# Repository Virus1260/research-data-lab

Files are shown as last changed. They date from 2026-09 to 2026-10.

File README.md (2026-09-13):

# Research Data Lab

> An interactive digital laboratory that transforms dense engineering research dossiers into visual, narrated, playable experiences.





## 🧪 Project #1 — Hosokawa AFD Pharma Freeze Dryer

**The AFD is not a conventional shelf/tray freeze dryer.** It is an agitated, jacketed, downward-conical vessel where product is frozen and dried while being continuously stirred, discharging as loose powder instead of vial cakes.

This interactive lab covers:
- 19 chapters from foundations → physics → build plan
- 8 interactive physics simulators (drag sliders, see real equations live)
- 74-item annotated Bill of Materials
- 34 academic & patent references
- Neural TTS narration for Chapter 03 (with transcript sync)
- Light & dark theme (light by default)

---

## ✨ Features

| Feature | Description |
|---|---|
| **Live Equation Playground** | Interact with Clausius-Clapeyron, sublimation rate, vacuum pumpdown & refrigeration equations |
| **Interactive Simulators** | 8 physics simulators wired to real engineering math |
| **Narration Engine** | Pre-generated audio with sentence-level transcript sync |
| **Light / Dark Theme** | Toggle via header (light default, persisted in `localStorage`) |
| **⌘K Command Palette** | Jump to any chapter, simulator, or BOM item instantly |
| **Proper Tables** | Professional data tables with hover states and filtering |
| **KaTeX Equations** | All formulas rendered with LaTeX precision |
| **Scrollytelling TOC** | Sticky mini-map with active section tracking |

---

## 🚀 Getting Started

```bash
# Clone the repository
git clone https://github.com/YOUR_USERNAME/research-data-lab.git
cd research-data-lab

# Install dependencies
npm install

# Start development server
npm run dev
```

Open [http://localhost:3000](http://localhost:3000) in your browser.

---

## 📁 Project Structure

```
research-data-lab/
├── app/                          # Next.js App Router
│   ├── layout.tsx                # Root layout (ThemeProvider, NarratorProvider)
│   ├── page.tsx                  # Archive — gallery of research capsules
│   └── [project]/
│       ├── page.tsx              # The Lab — project overview console
│       ├── [chapter]/page.tsx    # Exhibit — scrollytelling chapter reader
│       ├── bom/page.tsx          # The Bench — interactive BOM table
│       └── references/page.tsx   # The Shelf — source catalog
│
├── components/
│   ├── layout/
│   │   ├── Header.tsx            # Nav + theme toggle
│   │   ├── ThemeProvider.tsx     # Light/dark context (localStorage)
│   │   └── ThemeScript.tsx       # FOUC prevention inline script
│   ├── exhibit/
│   │   ├── ExhibitReader.tsx     # Markdown → HTML renderer with KaTeX
│   │   ├── KatexEquation.tsx     # LaTeX equation renderer
│   │   └── LawEquationsPlayground.tsx  # 4 live physics playgrounds
│   ├── simulators/               # 8 interactive simulators
│   │   ├── PhaseDiagramExplorer.tsx
│   │   ├── SublimationRateCalculator.tsx
│   │   ├── VacuumPumpdownSimulator.tsx
│   │   ├── CycleProfileScrubber.tsx
│   │   └── ...
│   ├── narrator/                 # Audio narration engine
│   │   ├── NarratorContext.tsx
│   │   └── NarratorDeck.tsx
│   └── command-palette/          # ⌘K search
│
├── research-data/
│   └── hosokawa-afd-freeze-dryer/
│       ├── project.config.ts     # Project metadata & act structure
│       ├── chapters/             # 19 MDX chapter files
│       ├── data/
│       │   ├── bom.json          # 74 BOM line items
│       │   └── references.json   # 34 cited references
│       ├── diagrams/             # 5 technical diagrams
│       └── audio/                # Neural TTS narration + manifests
│
├── lib/
│   ├── content.ts                # Server-side content readers
│   ├── physics.ts                # Physics formula implementations
│   └── types.ts                  # TypeScript interfaces
│
└── scripts/
    ├── generate_narration.py     # Azure Neural TTS pipeline
    ├── export_bom.py             # Excel → JSON BOM export
    └── migrate_chapters.py       # MD → MDX migration
```

---

## 🎨 Design System

**Obsidian Cleanroom** (dark) / **Lab Daylight** (light):

| Token | Dark | Light |
|---|---|---|
| Background | `#08090A` | `#F5F6F8` |
| Panel | `#0D0F12` | `#FFFFFF` |
| Cryo accent | `#7FD4FF` | `#2B8DC8` |
| Amber accent | `#E5A93C` | `#C8830A` |
| Typography | Geist Sans + Geist Mono | Same |

---

## 🔬 Interactive Simulators

1. **Phase Diagram Explorer** (Ch. 02) — Draggable P–T chart with state boundaries
2. **Sublimation Rate Calculator** (Ch. 11) — Heat-duty → drying time
3. **Vacuum Pumpdown Simulator** (Ch. 06/11) — Exponential evacuation curve
4. **Cycle Profile Scrubber** (Ch. 04) — 5-stage process timeline
5. **Comparative Pressure Detector** (Ch. 06) — Pirani vs. capacitance gauge
6. **Refrigeration Load Calculator** (Ch. 11) — Cooling duty & patent spec
7. **AFD Comparison Flip** (Ch. 03) — AFD vs. conventional lyophilizer
8. **Vessel Cross-Section** (Ch. 05) — Interactive 3D vessel exploded view

---

## 📖 Adding a New Research Project

1. Create `research-data/<your-project-slug>/`
2. Add `project.config.ts` (copy from `_template-project/`)
3. Add MDX chapters in `chapters/`
4. Add `data/bom.json` and `data/references.json`
5. Run `npm run dev` — the project auto-appears in the Archive

See [CONTRIBUTING.md](CONTRIBUTING.md) for the full schema.

---

## 🤖 Neural TTS Narration

```bash
pip install edge-tts
python scripts/generate_narration.py <chapter-slug>
# Outputs: public/research-data/<project>/audio/<chapter>.mp3
#          public/research-data/<project>/audio/<chapter>.manifest.json
```

---

## 🧠 Antigravity Brain Path

This project is maintained by the Antigravity IDE. The active brain/context for this project lives at:

```
C:\Users\Shekhar\.gemini\antigravity-ide\brain\c8a63233-3b28-442f-a429-51adf4072fb2\
```

To resume: open the Antigravity IDE and reference conversation `c8a63233-3b28-442f-a429-51adf4072fb2`.

---

## 📄 License

MIT © 2026 Research Data Lab

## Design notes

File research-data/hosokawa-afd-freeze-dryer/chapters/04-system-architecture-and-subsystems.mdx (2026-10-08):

---
title: "System Architecture & 17 Subsystems Overview"
chapterNumber: "04"
slug: "04-system-architecture-and-subsystems"
act: "Foundations & Flowsheets"
actId: "act-1"
readTime: "6 min read"
simulators: ['CycleProfileScrubber']
---

# 04 — System Architecture & 17 Subsystems Overview

::youtube[https://www.youtube.com/watch?v=91mCewt5t38]{title="Deep Dive into Nauta Mixing & Drying Technology - Educational Webinar" channel="HosokawaMicron" duration="47:36" context="Chapter 04 Architecture Deep Dive" caption="Engineering presentation detailing Vrieco-Nauta conical vacuum drying skid architecture, cantilevered drive integration, vacuum tightness, and auxiliary recovery circuits."}

Hosokawa Active Freeze Drying System — Integrated Production Skid

Hosokawa Vrieco-Nauta 5-VDC Complete Pilot Vacuum Dryer Skid

Stirred Freeze Dryer Process Flow Diagram (PFD) — Primary Operating Architecture

Hosokawa Industrial Vacuum Drying Plant Installation Schematic

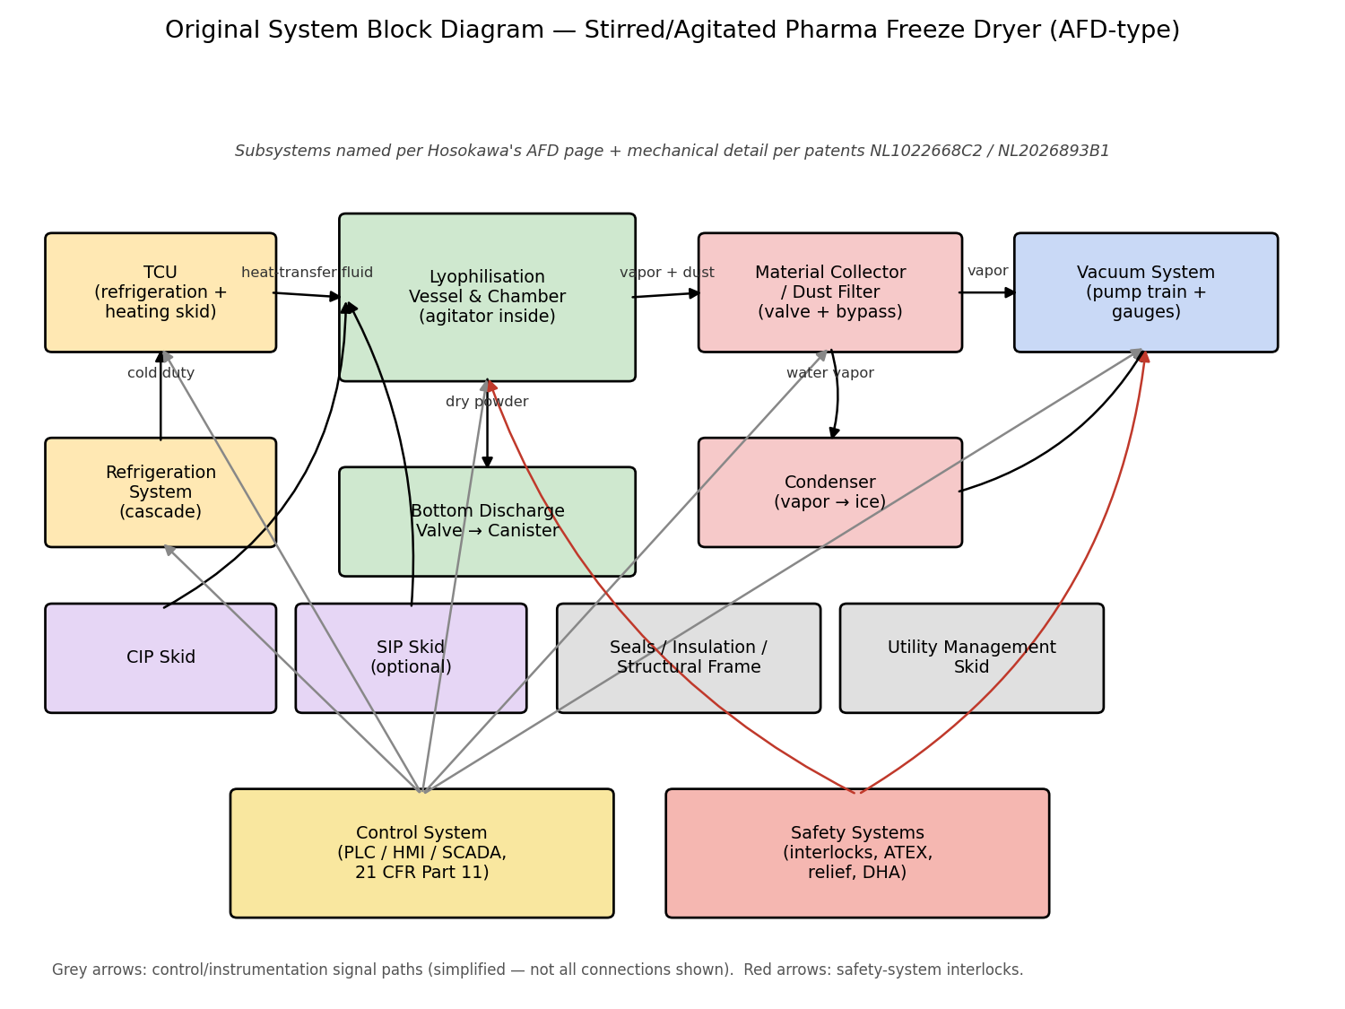
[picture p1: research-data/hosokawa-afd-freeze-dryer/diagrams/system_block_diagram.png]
AFD System Architecture Block Diagram


## 1. Top-Level Subsystem Architecture

Hosokawa Nauta Vacuum Dryer 3D Cutaway Showing Conical Shell and Agitator Dynamics

Vrieco-Nauta Vacuum Dryer Upward and Downward Powder Flow Vector Profile

Vrieco-Nauta Vacuum Dryer System with Pulse-Jet Filter, Condenser & Drain Tank

Hosokawa Controlled Randomization Kinematic Profile

Nauta Mixer Drive Assembly & 1 RPM Orbit Arm Subassembly

Adapting Nauta Conical Mixer for Vacuum Drying Applications

Hosokawa Mixing Spectrum: Nauta (Low Shear) vs CPM (Medium) vs Vitomix

The Hosokawa Active Freeze Dryer comprises 17 integrated mechanical, thermal, vacuum, and automation subsystems. Each subsystem is engineered for cGMP compliance, vacuum integrity down to $0.01\text{ mbar}$, and sterile cleanability:

<SystemArchitectureFlowChart />

---

## 2. Definitive 17-Subsystem Engineering Specification

| # | Subsystem | Operating Function & Physics | Authentic Design Specification | Core Chapter Reference |
|---|---|---|---|---|
| **1** | **Lyophilisation Vessel / Chamber** | Conical pressure/vacuum vessel supporting freeze and sublimation stages | Downward cone with 50% working fill volume constant ($h_{\text{fill}} = 0.794 \cdot h_{\text{cone}}$). Design: FV to +1.5 barg internal; 316L (1.4404) $\text{SF4 } R_a \le 0.38\,\mu\text{m}$. | [Chapter 05: Vessel & Agitator](file:///e:/git_desktop/research-data-lab/research-data/hosokawa-afd-freeze-dryer/chapters/05-vessel-chamber-agitator-and-materials.mdx) |
| **2** | **Agitator & Orbital Drive** | Convective bed circulation and boundary layer renewal | **10:1 Auger (~70 rpm) to Orbit (1–2 rpm) power split**. Cantilevered top-supported screw with **strictly zero bottom bearing**; 3–5 mm wall clearance. | [Chapter 05: Vessel & Agitator](file:///e:/git_desktop/research-data-lab/research-data/hosokawa-afd-freeze-dryer/chapters/05-vessel-chamber-agitator-and-materials.mdx) |
| **3** | **Vessel Jacket & TCU Skid** | Heat transfer fluid circulation for freezing and sublimation | Double jacket (half-pipe coil or dimpled). TCU circulates silicone oil (Syltherm XLT) across $-60^\circ\text{C}$ to $+80^\circ\text{C}$ ($+150^\circ\text{C}$ for SIP). | [Chapter 06: Refrigeration & Vacuum](file:///e:/git_desktop/research-data-lab/research-data/hosokawa-afd-freeze-dryer/chapters/12-refrigeration-vacuum-and-condenser-systems.mdx) |
| **4** | **Refrigeration Cascade** | Provides low-temperature cooling duty to TCU and ice condenser | Two-stage cascade system (R404A / R508B or natural R290 / R170). Evaporator duty sized to pull jacket down to $-55^\circ\text{C}$ within 60 min. | [Chapter 06: Refrigeration & Vacuum](file:///e:/git_desktop/research-data-lab/research-data/hosokawa-afd-freeze-dryer/chapters/12-refrigeration-vacuum-and-condenser-systems.mdx) |
| **5** | **Vacuum Pumping Skid** | Evacuates chamber to process vacuum ($0.05\text{ to }1.5\text{ mbar}$) | Dry screw vacuum pump paired with Roots mechanical booster. Dry design prevents oil backstreaming and handles solvent vapor traces. | [Chapter 06: Refrigeration & Vacuum](file:///e:/git_desktop/research-data-lab/research-data/hosokawa-afd-freeze-dryer/chapters/12-refrigeration-vacuum-and-condenser-systems.mdx) |
| **6** | **Heated Vapor Filter Dome** | Retains fines and routes sublimed vapor without condensation | Overhead dome **heated to +40 °C** via thermal fluid/electrical tracing. Features reverse-pulse dry N₂ blowback (4–6 bar) to dislodge powder cake. | [Chapter 06: Refrigeration & Vacuum](file:///e:/git_desktop/research-data-lab/research-data/hosokawa-afd-freeze-dryer/chapters/12-refrigeration-vacuum-and-condenser-systems.mdx) |
| **7** | **Bottom Discharge Valve** | Containment product discharge with zero dead leg | Sanitary **Ball Segment Valve** with inflatable silicone seal. Full-bore unobstructed flow into sterile transfer split-butterfly isolators. | [Chapter 05: Vessel & Agitator](file:///e:/git_desktop/research-data-lab/research-data/hosokawa-afd-freeze-dryer/chapters/05-vessel-chamber-agitator-and-materials.mdx) |
| **8** | **WIP/CIP Wash Skid** | Automated validated wash cycle without vessel disassembly | **Dual-loop distribution**: 5 cover spray nozzles at **115 mm pitch** (6 bar @ 9 m³/h) impinge drive head/seals; wall nozzles (3 bar) wet steep cone. | [Chapter 07: CIP, SIP & Utilities](file:///e:/git_desktop/research-data-lab/research-data/hosokawa-afd-freeze-dryer/chapters/14-cip-sip-sealing-insulation-and-utilities.mdx) |
| **9** | **SIP Clean Steam Skid** | In-place thermal sterilization of product contact surfaces | Saturated clean steam injection ($\ge 121.1^\circ\text{C}$ / $2.05\text{ bara}$, minimum 30 min hold) with automated condensate trapping at lowest points. | [Chapter 07: CIP, SIP & Utilities](file:///e:/git_desktop/research-data-lab/research-data/hosokawa-afd-freeze-dryer/chapters/14-cip-sip-sealing-insulation-and-utilities.mdx) |
| **10** | **Seals, Gaskets & Insulation** | Thermal barrier and hermetic vacuum boundary maintenance | USP Class VI / FDA PTFE-encapsulated O-rings and FFKM gaskets. Cryogenic-grade cellular glass or aerogel jacket insulation with 304 cladding. | [Chapter 07: CIP, SIP & Utilities](file:///e:/git_desktop/research-data-lab/research-data/hosokawa-afd-freeze-dryer/chapters/14-cip-sip-sealing-insulation-and-utilities.mdx) |
| **11** | **Process Instrumentation** | Continuous monitoring and comparative endpoint determination | Dual pressure measurement: Capacitance manometer (`PIT-101A`, true pressure) + Pirani gauge (`PIT-101B`). 4-wire Pt100 RTDs for bed/jacket profiling. | [Chapter 08: Instrumentation & Controls](file:///e:/git_desktop/research-data-lab/research-data/hosokawa-afd-freeze-dryer/chapters/16-instrumentation-and-electrical-hardware.mdx) |
| **12** | **Sanitary Process Valves & Lines** | Fluid and gas routing with EHEDG drainability | ASME BPE diaphragm valves for CIP/WFI utilities; high-vacuum butterfly and angle valves with position feedback for process gas lines. | [Chapter 08: Instrumentation & Controls](file:///e:/git_desktop/research-data-lab/research-data/hosokawa-afd-freeze-dryer/chapters/16-instrumentation-and-electrical-hardware.mdx) |
| **13** | **BPCS Control Platform** | Automated recipe execution and data historization | PLC-based Basic Process Control System (Siemens S7-1500 or Rockwell ControlLogix) with 21 CFR Part 11 compliant electronic audit trails. | [Chapter 20: Control System](file:///e:/git_desktop/research-data-lab/research-data/hosokawa-afd-freeze-dryer/chapters/17-control-system-architecture.mdx) |
| **14** | **Safety Instrumented System (SIS)** | Independent SIL-rated emergency shutdown and interlocks | Hardwired safety relays or safety PLC guarding against vessel over-pressurization, vacuum implosion, high jacket temp, and agitator stall. | [Chapter 20: Control System](file:///e:/git_desktop/research-data-lab/research-data/hosokawa-afd-freeze-dryer/chapters/17-control-system-architecture.mdx) |
| **15** | **Electrical & ATEX Infrastructure** | Power distribution and hazardous area compliance | VFDs for auger/orbit motors; Zone 20/21 internal ATEX classification for combustible active pharmaceutical dry powders. | [Chapter 08: Instrumentation & Controls](file:///e:/git_desktop/research-data-lab/research-data/hosokawa-afd-freeze-dryer/chapters/16-instrumentation-and-electrical-hardware.mdx) |
| **16** | **Structural Skid & Mezzanine** | Rigidity, vibration damping, and cleanroom integration | Tubular 304 stainless frame; through-the-wall cleanroom bulkhead design isolating technical utilities from GMP gray zone. | [Chapter 08: Instrumentation & Controls](file:///e:/git_desktop/research-data-lab/research-data/hosokawa-afd-freeze-dryer/chapters/16-instrumentation-and-electrical-hardware.mdx) |
| **17** | **Utility Management Skid** | Single-point connection header for plant services | Regulated headers for clean dry compressed air (CDA, 6 barg), gaseous dry nitrogen (N₂, 4–6 barg), WFI, chilled water, and drain cooling. | [Chapter 08: Instrumentation & Controls](file:///e:/git_desktop/research-data-lab/research-data/hosokawa-afd-freeze-dryer/chapters/16-instrumentation-and-electrical-hardware.mdx) |

---

## 3. How the Process Cycle Exercises the Subsystems

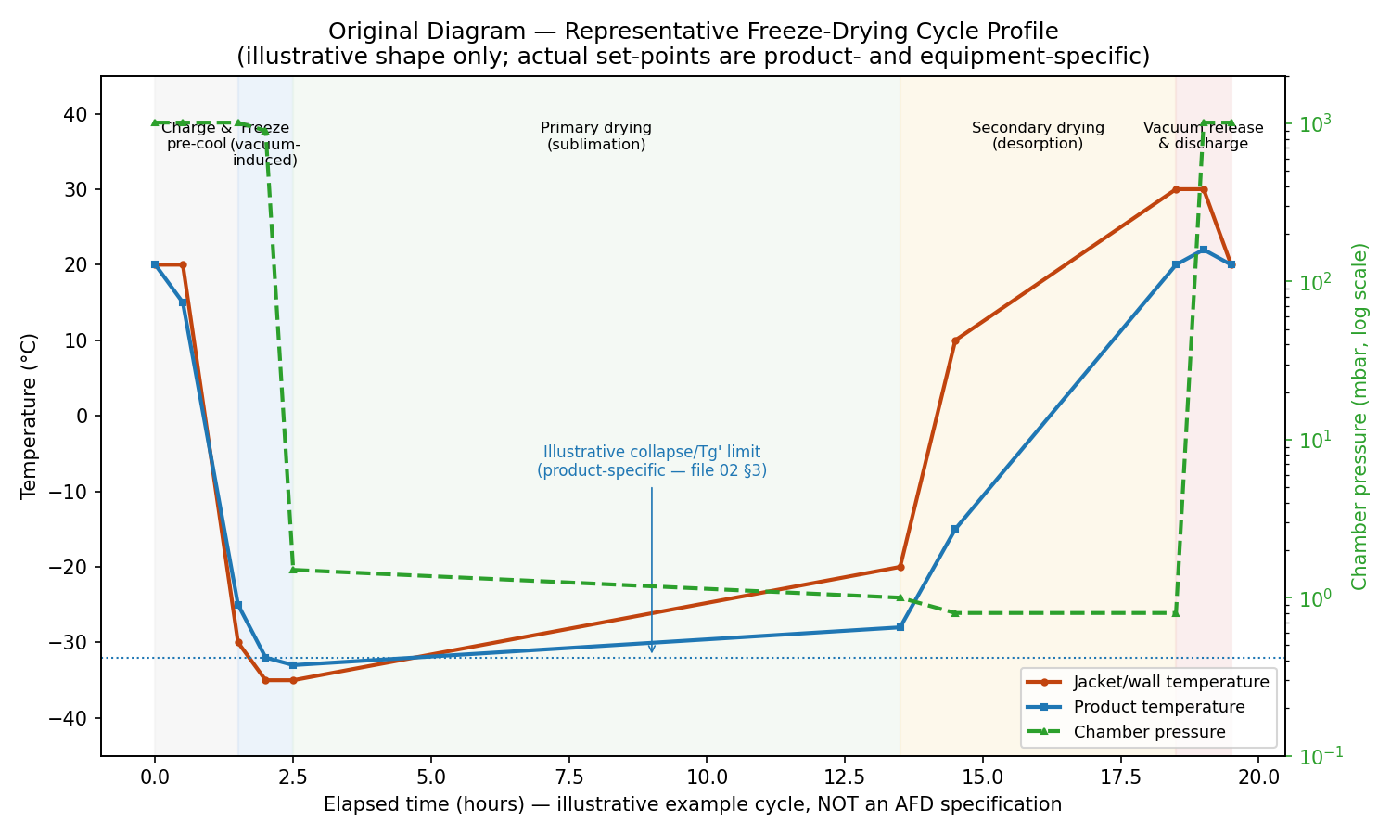
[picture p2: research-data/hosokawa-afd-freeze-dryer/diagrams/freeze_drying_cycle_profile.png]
Representative Freeze Drying Cycle Profile


1. **Aseptic Charging:** API solution or paste is charged via top sanitary port (`N1`) into the purged vessel (pre-inerted with N₂ to $<1\%\text{ O}_2$).
2. **Pre-Cooling & Agitated Granulation:** The TCU chills the vessel jacket to $-40^\circ\text{C}$. The cantilevered auger rotates at low speed (~20–40 rpm), gently tumbling the slurry against the cold wall to prevent bulk freezing into a solid block.
3. **Vacuum Flash Freezing:** The vacuum pump pulls chamber pressure down rapidly. Evaporative surface flash cooling pulls latent heat from within the droplets, fracturing the mass into free-flowing, porous snow granules.
4. **Primary Sublimation:** The vacuum is controlled at $0.05\text{ to }1.5\text{ mbar}$ by throttling valve `PV-102`. The TCU shifts to heating duty ($-10^\circ\text{C}$ to $+20^\circ\text{C}$), delivering $\Delta H_{\text{sub}} = 2,840\text{ kJ/kg}$ into the dynamic bed. Sublimed vapor passes through the +40 °C heated top dome.
5. **Secondary Desorption:** Pressure is lowered to $<0.05\text{ mbar}$ while the jacket is warmed to $+30^\circ\text{C}\text{ to }+40^\circ\text{C}$. Bound moisture desorbs until the Pirani and Capacitance manometer curves converge.
6. **Reverse-Pulse Blowback & Post-Blend:** High-pressure dry N₂ pulses dislodge fines from the filter elements; the auger runs for 5 minutes to homogenize the batch into a single uniform lot.
7. **Sterile Vacuum Release:** The vessel is vented to atmospheric pressure with sterile $0.2\,\mu\text{m}$-filtered nitrogen.
8. **Contained Discharge:** The bottom ball segment valve opens, discharging bulk powder directly into sterile continuous-liner bags or IBC totes.
9. **Automated WIP/CIP & SIP:** The dual-loop CIP skid washes the orbital head (6 bar @ 9 m³/h) and vessel walls (3 bar), followed by 121 °C clean steam sterilization.

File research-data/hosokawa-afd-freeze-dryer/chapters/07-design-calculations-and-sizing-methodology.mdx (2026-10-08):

---
title: "Design Calculations, Sizing Equations & Heat Transfer"
chapterNumber: "07"
slug: "07-design-calculations-and-sizing-methodology"
act: "Mechanical & Vessel Engineering"
actId: "act-2"
readTime: "10 min read"
simulators: ['SublimationRateCalculator', 'RefrigerationLoadCalculator', 'VacuumPumpdownSimulator']
---

# 07 — Design Calculations, Sizing Equations & Heat Transfer

All worked calculations below evaluate a representative **10 kg batch (10 L liquid) in a 20 L nominal vessel**. This batch matches Hosokawa's published 20 L Active Freeze Dryer model (10 L batch capacity, 0.8 kg/h sublimation capacity). This allows direct cross-checking of first-principles physics against commercial performance figures.

## 1. Sublimation rate and thermal duty

The core sublimation energy equation is:

$$Q = \dot{m} \cdot \Delta H_s$$

For ice, latent heat of sublimation is $\Delta H_s \approx 2{,}838\text{ kJ/kg}$.

Hosokawa specifies $\dot{m} = 0.8\text{ kg/h}$ for the 20 L model:

$$\dot{m} = \frac{0.8\text{ kg}}{3600\text{ s}} = 2.222 \times 10^{-4}\text{ kg/s}$$

$$Q = 2.222 \times 10^{-4}\text{ kg/s} \times 2{,}838{,}000\text{ J/kg} \approx 631\text{ W}$$

A thermal heat duty of 631 W sustains 0.8 kg/h sublimation. This thermal load is compact and readily delivered by an electric circulation TCU.

For a 10 kg batch with 90% water content (9.0 kg ice), primary drying time calculates as:

$$t_{\text{drying}} = \frac{9.0\text{ kg}}{0.8\text{ kg/h}} \approx 11.25\text{ hours}$$

This drying duration aligns with Hosokawa's patent range of 10 to 100 hours for industrial batches.

## 2. Required jacket heat-transfer area

Compute heat exchange surface using:

$$Q = U \cdot A \cdot \Delta T \implies A = \frac{Q}{U \cdot \Delta T}$$

- $U$: Overall heat transfer coefficient from jacket fluid to the agitated granular bed. For an actively stirred bed under vacuum, plan for $50\text{ to }200\text{ W/m}^2\text{K}$. Agitation eliminates the stagnant gas gap found in static vial freeze drying.
- $\Delta T$: Temperature difference between the jacket wall and the sublimation front (typically 10 to 30 K).

At $Q = 631\text{ W}$:

| Assumed $U$ ($\text{W/m}^2\text{K}$) | Required Area $A$ ($\text{m}^2$) at $\Delta T = 20\text{ K}$ |
|---|---|
| 50 | 0.63 |
| **100** | **0.32** |
| 150 | 0.21 |
| 200 | 0.16 |

At $U = 100\text{ W/m}^2\text{K}$, required area is $0.32\text{ m}^2$. Sizing a 20 L cone with a 25° half-angle yields exactly $0.32\text{ m}^2$ of internal wetted lateral area.

## 3. Freezing-stage refrigeration duty

Cooling a 10 kg aqueous charge (9.0 kg water, 1.0 kg solids) from +20 °C to -30 °C requires three thermal steps:

$$Q_1 = m \cdot c_{p,\text{liq}} \cdot \Delta T_1 = 10\text{ kg} \times 4.2\text{ kJ/kg}\cdot\text{K} \times 20\text{ K} = 840\text{ kJ}$$

$$Q_2 = m_{\text{water}} \cdot \Delta H_f = 9\text{ kg} \times 334\text{ kJ/kg} = 3{,}006\text{ kJ}$$

$$Q_3 = m \cdot c_{p,\text{ice}} \cdot \Delta T_2 = 10\text{ kg} \times 2.1\text{ kJ/kg}\cdot\text{K} \times 30\text{ K} = 630\text{ kJ}$$

$$\text{Total Thermal Removal } Q_{\text{total}} = 840 + 3{,}006 + 630 = 4{,}476\text{ kJ } (4.48\text{ MJ})$$

Hosokawa patents define optimum freezing rates between 0.1 °C/min and 10 °C/min:

| Target Freeze Time | Cooling Rate (50 °C delta) | Average Refrigeration Duty |
|---|---|---|
| 2.0 h | 0.42 °C/min | 0.62 kW |
| 1.0 h | 0.83 °C/min | 1.24 kW |
| 0.5 h | 1.67 °C/min | 2.49 kW |

Apply a 1.5x to 2.0x engineering factor to account for jacket thermal mass, ambient heat leak, and pump dissipation. Specify a 2.5 to 3.5 kW refrigeration unit.

## 4. Vacuum pump evacuation time

Dry chamber pump-down time follows the volumetric evacuation equation:

$$t = \left(\frac{V}{S}\right) \cdot \ln\left(\frac{P_1}{P_2}\right)$$

For a 20 L ($0.02\text{ m}^3$) dry vessel pumping from 1,013 mbar down to 1 mbar:

| Pump Displacement $S$ | Calculated Evacuation Time |
|---|---|
| 5 $\text{m}^3/\text{h}$ | ~100 s |
| 10 $\text{m}^3/\text{h}$ | ~50 s |
| 20 $\text{m}^3/\text{h}$ | ~25 s |
| 50 $\text{m}^3/\text{h}$ | ~10 s |

This calculation covers initial dry chamber drawdown only. During sublimation, water vapor volumetric flow dominates. At 1 mbar and -20 °C, 0.8 kg/h of vapor equates to over 250 L/s of volumetric gas flow. The cold condenser traps over 95% of this vapor, protecting the dry vacuum pump.

## 5. Agitator motor sizing

Granular agitated bed rheology under freezing vacuum cannot be modeled accurately from first principles alone.
- Hosokawa's 500 L Nauta industrial mixer operates with a 2.2 kW drive.
- A 20 L freeze dryer requires significantly less power (100 W to 250 W continuous).
- Size the drive motor for peak torque during the slush-to-ice phase inversion. Equip the drive with a variable frequency controller (VFD) and monitor motor current continuously.

## 6. External-pressure shell thickness: ASME UG-28

The vessel operates under external vacuum pressure (1.013 bar differential):
- Thin conical shells fail by elastic buckling rather than plastic yielding.
- Sizing follows ASME Section VIII Division 1, paragraph UG-28.
- The engineer assumes an initial wall thickness $t$, computes diameter-to-thickness ($D_o/t$) and length-to-diameter ($L/D_o$) ratios, and retrieves Strain Factor $A$ from Section II Part D Subpart 3 Figure G.
- Using Factor $A$ and design metal temperature, read Stress Factor $B$ from material charts.
- Allowable external working pressure computes as:

$$P_a = \frac{4 \cdot B}{3 \cdot (D_o/t)}$$

Verify that $P_a \ge 1.033\text{ bar}$ plus your required safety margin.

## 7. External pressure tooling methodology: Division 1 vs Division 2 vs PV Elite

Understanding the calculation methodology determines software implementation:

1. **ASME Section VIII Division 1 (UG-28)**:
   - Uses empirical look-up charts. Factor $A$ comes from Figure G. Factor $B$ derives from material stress curves in Section II Part D.
   - These curves represent proprietary ASME compiled data. Do not use AI models to guess curve values.
2. **ASME Section VIII Division 2 (Part 4.4 - Miller Method)**:
   - Formulated as closed-form algebraic equations.
   - Eliminates chart lookups.
   - Readily programmed into automated computational tools.
3. **PV Elite and Commercial Pressure Vessel Solvers**:
   - Industry-standard validated solver for ASME certified code calculations.
   - Integrates ASME material databases and safety factors.
4. **Interactive Vessel Sizing Suite (Built in this Lab)**:
   - Provides preliminary sizing, live geometric exploration, and nozzle coordination.
   - Implements the open, published **Windenburg-Trilling equation** for classical elastic buckling:

$$P_{\text{cr}} = \frac{2.42 \cdot E \cdot (t / D_o)^{5/2}}{(1 - \nu^2)^{3/4} \cdot \left[\frac{L}{D_o} - 0.45 \cdot (t / D_o)^{1/2}\right]}$$

   - Applying a structural safety factor of 3.0 gives the preliminary allowable pressure:

$$P_{\text{allowable}} = \frac{P_{\text{cr}}}{3.0}$$

**Fabrication Rule**: Use the Sizing Suite for rapid dimensional optimization and nozzle scheduling. Perform final certified thickness validation in PV Elite prior to cutting metal.

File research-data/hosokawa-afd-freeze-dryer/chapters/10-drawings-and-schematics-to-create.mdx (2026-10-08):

---
title: "Workshop Fabrication Drawings, Schematics & GA Layouts"
chapterNumber: "10"
slug: "10-drawings-and-schematics-to-create"
act: "Mechanical & Vessel Engineering"
actId: "act-2"
readTime: "3 min read"
simulators: []
---

# 10 — Workshop Fabrication Drawings, Schematics & GA Layouts

The drawings and schematics below (phase diagram, vessel cross-section, system block diagram, refrigeration cascade, cycle profile, P&ID, control architecture, and ISA-88 batch structure) are conceptual/explanatory originals created for this package:

<EngineeringDiagramsGallery />

## Recommended drawing package

| # | Drawing | Purpose | Typical format |
|---|---|---|---|
| 1 | **General arrangement (GA) drawing** | Overall machine footprint, height, service-access clearances, and how all major subsystems (vessel, TCU, vacuum skid, control panel, frame) sit relative to each other | Orthographic views (front/side/top) + isometric |
| 2 | **Vessel fabrication drawing** | Full dimensioned geometry of the conical vessel and jacket: shell thickness, cone angle, cylindrical section height (if used), jacket compartment dimensions, all nozzle/port locations with size and orientation, support-lug locations | Detailed fabrication drawing, code-stamped if pursuing a certified pressure/vacuum vessel |
| 3 | **Agitator drawing** | Mixing-element geometry (screw/paddle/ribbon), shaft dimensions, wall-clearance callouts at multiple heights up the cone, drive-end interface | Fabrication drawing with clearance tolerances explicitly called out (file 05 §3, file 10 §3) |
| 4 | **Process & Instrumentation Diagram (P&ID)** | Every process line, valve, instrument, and interlock in the system, using standard ISA/ANSI instrumentation symbols — the single most important document for both build and later validation/commissioning | Standard P&ID symbology; this is the document file 04's block diagram should evolve into once your design is fixed |
| 5 | **Piping isometrics** | Physical routing of vacuum lines, jacket fluid lines, CIP/SIP lines, and utility lines, with support locations | Standard isometric piping drawings |
| 6 | **Electrical single-line diagram** | Power distribution from main disconnect through to every motor, heater, and control circuit, with breaker/fuse ratings | Standard electrical single-line format |
| 7 | **Control panel layout & wiring diagram** | Physical panel layout and full point-to-point wiring for the PLC/HMI system | Standard electrical panel drawing practice |
| 8 | **I/O list** | Every PLC input and output, tag name, signal type, range, and the field device it connects to | Spreadsheet/table, cross-referenced to the P&ID |
| 9 | **Hazardous-area (ATEX) zoning drawing** | Marked-up GA or floor plan showing Zone 20/21/22 dust boundaries around the material collector/discharge area, and the equipment rating required in each zone | Overlay on the GA drawing, developed alongside the Dust Hazard Analysis (file 09) |
| 10 | **Structural frame/skid drawing** | Frame member sizes, support-point locations matching the vessel's actual lug/support-ring positions, foundation/floor loading | Standard structural fabrication drawing |
| 11 | **CIP/SIP schematic** | Spray coverage, chemical dosing points, steam distribution points and traps (if SIP-equipped) | Schematic, cross-referenced to the P&ID |
| 12 | **Cycle/recipe logic flowchart** | The actual control-system sequence: every step, transition condition, interlock check, and alarm condition through charge → freeze → primary dry → secondary dry → discharge → CIP/SIP | Flowchart, becomes the basis for PLC program structure and later OQ test scripts (file 14) |

## Suggested sequencing

Per the staged fabrication approach in file 10 §4: produce drawings 1–3 first (vessel/agitator geometry) alongside your file-11 sizing calculations, prove the geometry with a non-vacuum mockup, *then* finalize drawing 2 for the real vacuum-rated vessel commission. Drawings 4, 8, and 12 (P&ID, I/O list, cycle logic) should be developed together, since each constrains the others — a common and efficient practice is to draft the cycle logic flowchart first (what does the machine actually need to do, step by step), derive the P&ID from what that logic requires the machine to sense and actuate, and derive the I/O list directly from the finished P&ID.

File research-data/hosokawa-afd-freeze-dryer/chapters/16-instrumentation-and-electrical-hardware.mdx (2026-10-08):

---
title: "Instrumentation Sensors, Electrical Hardware & Skid Frame"
chapterNumber: "16"
slug: "16-instrumentation-and-electrical-hardware"
act: "Electrical, Controls & Safety Automation"
actId: "act-4"
readTime: "6 min read"
simulators: []
---

# 16 — Instrumentation Sensors, Electrical Hardware & Skid Frame

## 1. Process Instrumentation Architecture

| Measurement | Primary Sensor & Loop Tag | Functional Principle & Operating Metric |
|---|---|---|
| **Chamber Absolute Pressure** | Capacitance Manometer (`PIT-101A`) | Diaphragm deflection measuring true mechanical pressure ($0.01 - 10\text{ mbar}$) independently of gas composition. Drives vacuum throttle valve `PV-102`. |
| **Comparative Diagnostic Pressure** | Pirani Thermal Gauge (`PIT-101B`) | Heated filament gauge; reads ~1.6× higher when pure water vapor dominates. Convergence of `PIT-101B` with `PIT-101A` detects sublimation completion. |
| **Condenser Pressure** | Capacitance + Pirani Pair (`PIT-201A/B`) | Monitors condenser vapor load and ice accumulation; enables chamber-to-condenser pressure delta monitoring. |
| **Jacket Supply & Return Temperature** | 4-Wire Pt100 RTDs (`TT-201`, `TT-202`) | Feeds TCU temperature control loop (`TIC-201`) modulating thermal fluid mixing across $-60^\circ\text{C}\text{ to }+80^\circ\text{C}$. |
| **Dynamic Bed Temperature** | Fast-Response Thermocouple Rake (`TT-101`) | Measures core bed temperature; interlocked to ensure product stays below collapse temperature ($T_{\text{bed}} < T_c$). |
| **Heated Top Dome Temperature** | Pt100 RTD (`TT-102`) | Feeds dome heater loop (`TIC-102`), maintaining dome wall at **+40 °C** to prevent water vapor condensation and filter cake blinding. |
| **Agitator Kinematic Feedback** | Torque Transducer / Current (`JIT-101`) | Monitors 10:1 auger drive torque; rising torque indicates slurry crystallization during vacuum flash freezing. |
| **Filter Differential Pressure** | Differential Transmitter (`PDT-102`) | Monitors pressure drop across porous filter media ($\Delta P \ge 50\text{ mbar}$ triggers reverse N₂ blowback `XV-104`). |
| **WIP/CIP Cover Ring Pressure & Flow** | Sanitary Transmitter (`PIT-701`, `FT-701`) | Confirms 6.0 bar @ 9.0 m³/hr to the 5 fixed spray nozzles (115 mm pitch) over the orbital drive head per Hosokawa Drawing `8390105_1`. |
| **WIP/CIP Wall Wash Pressure** | Sanitary Transmitter (`PIT-702`) | Confirms 3.0 bar wash water supply to downward-angled cone wall wetting nozzles per Hosokawa Drawing `8390106_1`. |
| **SIP Sterilization Temperature** | Multi-Point RTD Sensors (`TT-501` to `TT-506`) | Cold spot monitoring during $121.1^\circ\text{C}$ steam sterilization (vessel bottom, discharge valve, and filter exhaust). |

---

## 2. Sanitary Process & Vacuum Valve Selection

- **Vacuum Throttling & Bypass Valves (`PV-102`, `XV-103`):** High-vacuum bellow-sealed angle and butterfly valves with fast pneumatic positioning, managing vapor evacuation and powder recirculation per Hosokawa patent NL2026893B1.
- **Reverse-Pulse Blowback Solenoid (`XV-104`):** High-speed pneumatic valve delivering 4–6 bar dry nitrogen pulses to dislodge collected powder fines from the overhead filter elements.
- **Sanitary Ball Segment Valve (`XV-105`):** Pneumatically operated bottom discharge valve with an inflatable USP Class VI elastomer seal, delivering zero dead space and hermetic vacuum retention.
- **Sanitary Utility Valves (`FV-701`, `FV-702`):** ASME BPE compliant diaphragm valves for CIP distribution, electropolished 316L with PTFE diaphragms.
- **Sterile Gas Break Valve (`XV-106`):** Spring-return fail-closed valve fed with $0.2\,\mu\text{m}$ sterile-filtered nitrogen for controlled atmospheric recovery.

## 3. Control system (PLC/HMI/SCADA)

Hosokawa states explicitly: "**Control system, 21 CFR Part 11 compliant**." Generic architecture for a system like this, consistent with both the AFD's stated compliance target and standard industrial-automation practice:

- **PLC** (programmable logic controller) executes the actual recipe logic: sequencing through freeze/vacuum-draw/primary-dry/secondary-dry/discharge/CIP/SIP steps, reading all instrumentation, driving all valves and drives, and enforcing interlocks (see file 09).
- **HMI** (human-machine interface) — operator screen for recipe selection, live trending of pressure/temperature, alarm display, and manual override where permitted.
- **Data historian / SCADA layer** — logs every batch's process data continuously, which is what makes GMP batch-record generation and regulatory compliance possible at all; this is also where **21 CFR Part 11** requirements bite hardest (see below).
- **GAMP 5** (ISPE's "Good Automated Manufacturing Practice," version 5) is the risk-based framework the pharma industry uses to validate this class of computerized system — it categorizes software (from off-the-shelf infrastructure through configured/customized applications) and scales validation rigor accordingly, rather than demanding the same exhaustive testing for every line of code regardless of risk.
- **21 CFR Part 11** governs electronic records and electronic signatures specifically: audit trails that cannot be altered or deleted, secure user access levels, electronic signatures tied to specific actions (e.g., batch release), and record retention. This is a *regulatory* requirement layered on top of the *engineering* PLC/HMI/historian system — a system can be technically well-built and still fail a Part 11 assessment if, e.g., audit trails can be disabled by an operator, or electronic signatures aren't properly bound to the record they approve. File 14 covers this distinction (build it right vs. prove it's right) in depth.
- For a prototype/educational build, a modern industrial PLC (Siemens S7-1200/1500, Allen-Bradley CompactLogix, or similar) with a standard HMI panel gives you the same architecture pattern at a fraction of the validation overhead — you simply won't (and, per file 14, legally shouldn't) claim GMP/Part 11 compliance for it without the full qualification and software-validation program that requires.

## 4. Electrical system

- **Motor drives**: agitator drive motor (with VFD for speed control, given the freeze/dry-stage speed differences the patents imply), TCU pump and compressor motors, vacuum pump motors — all standard industrial motor/VFD selection, no freeze-dryer-specific electrical technology involved.
- **ATEX-rated equipment** required in any zone where combustible dust is present at meaningful concentration — most relevantly, around the material collector, filter housing, and product discharge/collection point, where dry, fine pharmaceutical powder is directly handled. See file 09 for the hazard basis; practically, this means selecting motors, sensors, junction boxes, and lighting in that zone with the appropriate Zone 20/21/22 dust rating (per the ATEX equipment-category system) rather than standard industrial-rated hardware.
- **Control power segregation**: standard industrial-panel practice — separate, clearly labeled circuits for control logic (24VDC typical) vs. motor/heater power, with appropriately rated disconnects and e-stop circuits (see file 09) wired independently of the PLC logic so an emergency stop functions even if the PLC itself has faulted.

## 5. Structural frame

Conical Mixer Structural Mezzanine Platform & Load Cell Skid System

- A **skid/frame** supports the vessel, its jacket, the agitator drive assembly above the lid, and (depending on layout) the material collector and vacuum piping.
- Given the vessel's cone-point-down orientation and top-mounted drive, the frame's key structural jobs are: (1) carrying the vessel's dead weight plus full product load at the frame's support points (typically a support ring or lugs partway up the conical shell, not the point-down tip); (2) resisting the agitator drive's reaction torque without transmitting objectionable vibration into the vessel/agitator wall-clearance tolerance (file 05 §3); and (3) providing safe operator access — a platform or steps if the lid/top fittings sit above comfortable reach height, which they will on any vessel above roughly the 60–100 L size range per the Nauta-mixer height-vs-volume table in file 03 §3.
- **Vibration isolation** between rotating equipment (agitator drive, vacuum pumps, refrigeration compressors) and the frame is worth designing in from the start — both for instrument reading stability (a vibrating capacitance manometer or torque sensor is a noisy signal) and for the agitator's tight wall-clearance tolerance, which vibration can effectively close to zero at the worst moment.

## 6. Piping

- **Process/vacuum piping**: sized for the pump's rated flow at the expected operating pressure (see file 11's vacuum pump-down calculation) — vacuum piping in particular should be kept as short and large-diameter as practical, since conductance losses in a low-pressure gas line scale unfavorably with length and unfavorably with the fourth power of a reduction in diameter (standard vacuum-engineering practice, not freeze-dryer-specific).
- **Jacket/TCU piping**: sized for the heat-transfer fluid's flow rate and viscosity at the coldest operating temperature (silicone oil viscosity rises substantially as it approaches −55 °C, which can meaningfully derate a pump's real flow delivery versus its room-temperature-water rating — worth checking against the specific fluid's datasheet rather than assuming).
- **Utility piping** (CIP water, compressed air, steam if SIP-equipped) sized per standard industrial practice for the respective utility.
- All product-contact and CIP/SIP-wetted piping should follow the same **ASME BPE sanitary tube/fitting practice** as the vessel itself (file 05 §4) — orbital-welded (not threaded or manually TIG-stitched) joints, crevice-free fittings, and consistent slope/drainability so no wash or rinse fluid can pool.

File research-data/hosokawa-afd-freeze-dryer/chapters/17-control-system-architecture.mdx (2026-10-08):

---
title: "PLC / SCADA Control Architecture & Industrial Network"
chapterNumber: "17"
slug: "17-control-system-architecture"
act: "Electrical, Controls & Safety Automation"
actId: "act-4"
readTime: "5 min read"
simulators: []
---

# 17 — PLC / SCADA Control Architecture & Industrial Network

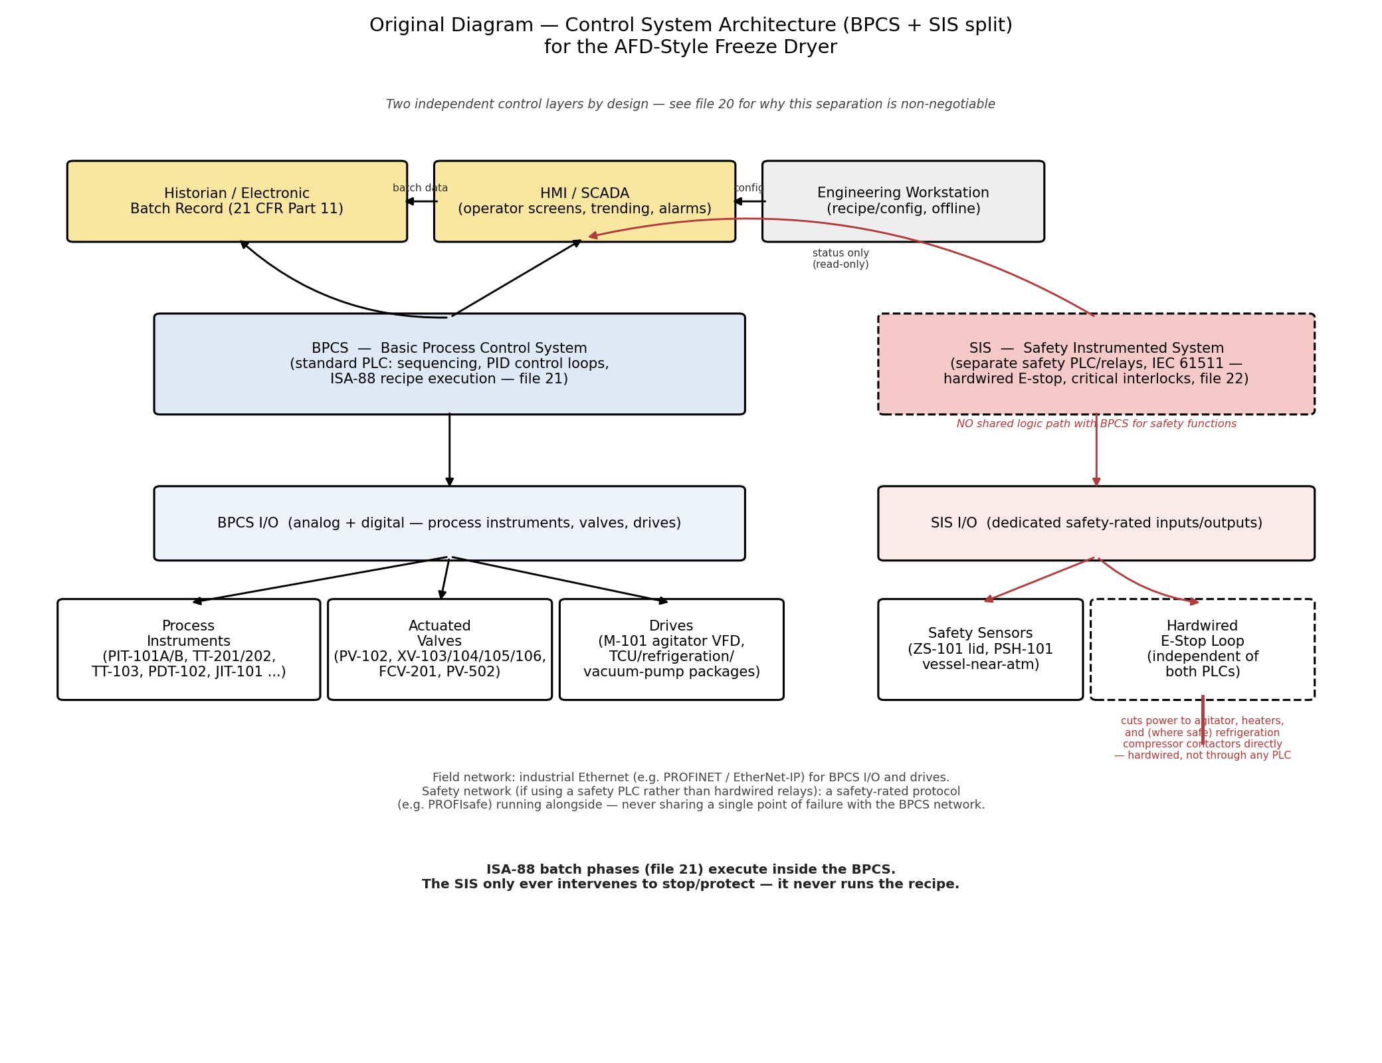
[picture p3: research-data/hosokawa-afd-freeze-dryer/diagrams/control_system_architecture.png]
Control System Architecture — BPCS vs SIS


<AutomationHierarchyChart />

## 1. The one idea that makes everything else make sense

A modern industrial control system for equipment like this is really **two separate systems wearing one HMI screen**:

1. **BPCS — Basic Process Control System.** The "normal" PLC. It runs the recipe, holds temperatures and pressures at setpoint, opens and closes valves in sequence, and logs data. If it glitches, the worst case is a ruined batch.
2. **SIS — Safety Instrumented System.** A separate, simpler, independent system whose *only* job is to force the equipment into a safe state when something specific and dangerous happens — lid opened under vacuum, emergency stop pressed, oxygen depleted in the room. If the BPCS completely fails or freezes, the SIS still works, because it was never depending on the BPCS in the first place.

This split isn't extra bureaucracy — it's the entire point. **IEC 61511**, the international standard for safety instrumented systems in the process industries, exists precisely because history is full of incidents where a single control system was asked to both run the process *and* protect people from it, and a single software bug or logic error took out both jobs at once. Keeping them physically and logically separate means one failure mode can't do that.

Concretely, on this machine: the emergency stop loop (`ESD-001`) is **hardwired** — a physical relay circuit that cuts power to the agitator, heaters, and (where safe to do so) the refrigeration compressor contactors directly. It does not pass through the PLC's software at any point. Even if the BPCS PLC has completely crashed, pressing that button still works.

## 2. The four layers, bottom to top

1. **Field devices** — the actual instruments and valves on the P&ID (file 19): `PIT-101A/B`, `TT-201/202`, `JIT-101`, `PV-102`, `XV-103/104/105/106`, etc. Split cleanly by which system owns them — ordinary process instruments belong to the BPCS; `ZS-101`, `PSH-101`, and the E-stop loop belong to the SIS and nothing else.
2. **I/O** — where field signals physically land: analog input/output cards for continuous signals (4–20 mA, RTD), digital input/output for on/off signals (limit switches, run feedback, valve open/closed confirmation). The SIS uses its own dedicated, safety-rated I/O — never sharing a card or a rack with BPCS I/O, so a BPCS I/O card fault can't also blind the safety system.
3. **Controllers** — the BPCS PLC (running the ISA-88 recipe logic from file 21) and the SIS (either a certified safety PLC or, for a smaller/prototype build, simple hardwired safety relays — both are legitimate approaches; a safety PLC is more flexible as the interlock list grows, hardwired relays are simpler to verify and are a very reasonable choice for a first build).
4. **Supervisory layer** — HMI/SCADA (what the operator actually looks at: live values, trends, alarms, manual controls where permitted), a historian/electronic batch record (every batch's data, logged continuously — this is what a real GMP batch record is built from, file 14), and an engineering workstation for offline recipe/configuration work.

Hosokawa Micron SCADA HMI Mimic Screen — Main Process Overview & Motor Controls

## 3. What talks to what (and, just as importantly, what doesn't)

- The BPCS talks to the HMI/SCADA and the historian freely — that's its whole job.
- The SIS talks to the HMI **read-only** — an operator can *see* that a safety interlock has tripped and why, but the HMI (and by extension, the BPCS) has no path to override or reset a safety trip through software. Resetting a genuine safety trip is normally a deliberate physical/procedural action, precisely so a software bug can't quietly clear a safety condition on its own.
- The SIS does not execute any part of the recipe. It only ever watches a small number of specific, safety-relevant signals and forces specific safe-state actions when they occur (file 22's cause-and-effect matrix is the complete list of what those are on this machine).

## 4. Networks

- **Field network for the BPCS**: a standard industrial Ethernet protocol — PROFINET or EtherNet/IP are the two you'll see most often — connecting the PLC to remote I/O, VFDs (like the agitator drive), and the HMI.
- **Safety network**, if you use a safety PLC rather than hardwired relays: a safety-rated protocol running alongside the standard network (PROFIsafe is the common example on a PROFINET-based system) — designed so that even sharing physical cabling, the safety data is checksummed and validated independently, and a corrupted BPCS message can never be mistaken for a valid safety command.
- For a first build, it's completely reasonable to skip a safety PLC and safety network entirely and use simple, physically separate hardwired relay logic for the handful of SIS functions in file 22 — this is simpler to build, simpler to verify by testing, and loses none of the core "independent from the BPCS" property that actually matters. Move to a safety PLC later if the interlock list grows enough that relay wiring becomes unwieldy.

## 5. Where the ISA-88 recipe logic (file 21) actually lives

All of it sits inside the BPCS, as software. The SIS never runs a step of the recipe — it only ever watches and, if needed, stops. Keeping this boundary completely clean (recipe logic in the BPCS, protection logic in the SIS, and nothing shared between them) is the single habit most worth building correctly from your very first prototype, because retrofitting the separation into a system that was built without it is far harder than building it in from day one.

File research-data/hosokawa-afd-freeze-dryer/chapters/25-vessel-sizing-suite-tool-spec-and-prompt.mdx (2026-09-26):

---
title: "Vessel Sizing Suite: Tool Specification & Parametric Engineering Architecture"
chapterNumber: "25"
slug: "25-vessel-sizing-suite-tool-spec-and-prompt"
act: "Automation, P&ID & CAD"
actId: "act-5"
readTime: "12 min read"
simulators: ['VesselSizingSuite']
---

# 25: Vessel Sizing Suite: Tool Specification & Parametric Engineering Architecture

This specification formalizes the physical models from Chapter 05 §1a/§1b and Chapter 11 §6-7 into an operational, interactive mechanical sizing architecture: a parametric conical freeze-dryer suite matching Hosokawa's published 10-model industrial spectrum (1 L to 1,500 L nominal).

## 1. What this tool is and what it is not

**It is**: a real-time, interactive engineering explorer for conical freeze-dryer vessel geometry across the full industrial size range (1 L to 1,500 L nominal). It establishes dynamic coupling between batch working volume, cone half-angle ($\alpha = 20^\circ$ to $35^\circ$), top major diameter ($D_{\text{major}}$), apex minor diameter ($D_{\text{minor}}$), height stack, lateral transfer area, 50 mm annular jacket hydrodynamics, ASME Section VIII UG-32 formed heads, and elastic vacuum buckling stability. It exports dimensionally certified nozzle schedules directly for CAD modeling and P&ID integration (Chapter 24).

**It is not**: a substitute for certified ASME BPVC Section VIII Division 1 or Division 2 stress calculations performed in licensed software such as PV Elite. Chapter 11 §7 codifies this clear boundary: this sizing suite generates preliminary mechanical architecture, geometric envelopes, and thermal feasibility bounds. Final nozzle reinforcement pads, knuckle high-stress concentrations, seismic anchoring, and certified full-vacuum buckling margins must be stamped in PV Elite prior to cutting metal.

---

## 2. Interactive Core Calculation Workbenches

Every equation in this sizing methodology is dynamic and interactive. Adjust the sliders below to explore the non-linear coupling across vessel dimensions, non-linear fill heights, heat transfer margins, ASME heads, and external pressure limits.

### 2.1 Conical Shell Geometry Workbench (Height, Diameter, Slant & Lateral Area)

In a conical vessel, volume $V$ is governed by total height $h$ and half-angle $\alpha$:
$$V = \frac{\pi}{3} \cdot \tan^2(\alpha) \cdot h^3 \implies h = \left[\frac{3 \cdot V}{\pi \cdot \tan^2(\alpha)}\right]^{1/3}$$

The interactive workbench below solves the complete geometric state vector ($h$, $D$, $L_{\text{slant}}$, and $A_{\text{lat}}$) for any volume and angle:

::ConeGeometryWorkbench

---

### 2.2 The Non-Linear Cone Fill Height Insight (V ∝ h³)

In a conical dryer, volume scales with the **cube** of vertical height. While a cylindrical vessel fills linearly ($V \propto h$), a cone concentrates volume at the top. Filling a conical vessel to 50% working volume raises the liquid surface to:
$$h_{\text{fill}} = h \cdot (0.5)^{1/3} \approx 0.794 \cdot h \quad (79.4\%\text{ of total height})$$

This leaves only $20.6\%$ linear freeboard. Attempting to fill to $80\%$ volume pushes the liquid surface to $92.8\%$ of total height (leaving only $7.2\%$ freeboard), suffocating the orbiting orbital screw agitator, blocking subliming vapor escape paths, and triggering severe dry cake entrainment into the top vacuum filter plenum.

::NonlinearFillHeightWorkbench

---

### 2.3 Sublimation Heat Duty & Annular Heat-Transfer Area Cross-Check

The sublimation process requires continuous latent heat input through the conical jacketed wall ($Q = \dot{m} \cdot \Delta H_s$). The jacket surface area must satisfy:
$$A_{\text{req}} = \frac{Q}{U \cdot \Delta T}$$

If the conical lateral surface area $A_{\text{lat}}$ is insufficient to transfer this thermal load, the vessel design requires a straight cylindrical shell extension at the top to close the thermal deficit. Explore the trade-offs below:

::JacketSurfaceAreaWorkbench

---

### 2.4 ASME Section VIII UG-32 Dished Head Thickness Calculator

The top vessel closure must withstand internal clean steam-in-place (SIP) pressure up to 3.0 to 3.5 barg at 135°C under ASME BPVC Section VIII Division 1 UG-32 rules:
- **Torispherical (ASME Flanged & Dished)**: $L = D$, $r = 0.06D$, stress coefficient $M = \frac{3 + \sqrt{L/r}}{4} \approx 1.77$:
  $$t = \frac{P \cdot L \cdot M}{2SE - 0.2P}$$
- **2:1 Semi-Ellipsoidal**: $L = 0.9D$, $r = 0.17D$, stress coefficient $K = 1.0$:
  $$t = \frac{P \cdot D \cdot K}{2SE - 0.2P}$$
- **Flat Bolted Blind Flange**: Structurally inefficient under vacuum; ASME guidelines restrict flat heads to diameters $\le 300\text{ mm}$.

::HeadThicknessWorkbench

---

### 2.5 Preliminary Vacuum Buckling & External Pressure Analysis

During freeze-drying, the vessel operates under deep vacuum (0.01 to 0.1 mbar) while the thermal fluid jacket operates at positive pressure (1.5 to 3.0 barg), producing severe net external collapsing pressure. Classical elastic shell buckling is governed by the Windenburg-Trilling formulation:
$$P_{\text{cr}} = \frac{2.42 \cdot E \cdot (t / D_o)^{5/2}}{(1 - \nu^2)^{3/4} \cdot \left[\frac{L}{D_o} - 0.45 \cdot (t / D_o)^{1/2}\right]}$$

With an ASME Section VIII design factor of safety $\text{FS} = 3.0$, allowable external vacuum pressure $P_{\text{allowable}} = P_{\text{cr}} / 3.0$ must strictly exceed atmospheric differential pressure (1.013 bar).

::BucklingPressureWorkbench

---

## 3. Parametric Vessel Sizing & Fabrication Suite (Live CAD Simulator)

Below is the live, unified parametric sizing application. It integrates the 10 Hosokawa model presets, dynamic cone half-angle modulation, formed head profile selection, full 50 mm annular jacket modeling, and an adaptive engineering fabrication sketch with dual-theme Paper CAD and Deep Blueprint modes.

::VesselSizingSuite

---

## 4. Humanized Technical Specification & Engineering Matrices

### 4.1 Hosokawa AFD Published Model Range & Working Volume Matrix

Hosokawa Micron markets 10 standard production sizes of the AFD Conical Freeze-Dryer. In all standard models, the maximum allowable batch working volume is set to **exactly 50% of the nominal cone volume** to safeguard the orbital screw agitator mechanics and ensure unimpeded vapor sublimation disengagement.

| Model Designation | Nominal Volume $V_{\text{nom}}$ | Max Batch Volume $V_{\text{work}}$ (50%) | Sublimation Capacity $\dot{m}$ | Top Major Diameter $D_{\text{major}}$ | Cone Height $h_{\text{cone}}$ ($\alpha=25^\circ$) | Conical Lateral Area $A_{\text{lat}}$ | Apex Discharge Bore | Industrial Application Scale |
| :--- | :--- | :--- | :--- | :--- | :--- | :--- | :--- | :--- |
| **AFD-1** | 1.0 L | 0.5 L | 0.10 kg/h | 14.1 cm (141 mm) | 15.1 cm (151 mm) | 0.036 m² | DN80 (3" Tri-Clamp) | Benchtop R&D / Feasibility |
| **AFD-5** | 5.0 L | 2.5 L | 0.30 kg/h | 24.1 cm (241 mm) | 25.8 cm (258 mm) | 0.106 m² | DN80 (3" Tri-Clamp) | Formulation Development |
| **AFD-20** | 20.0 L | 10.0 L | 0.80 kg/h | 38.2 cm (382 mm) | 41.0 cm (410 mm) | 0.267 m² | DN100 (4" Tri-Clamp) | Pilot Plant / Clinical Phase I |
| **AFD-60** | 60.0 L | 30.0 L | 1.70 kg/h | 55.1 cm (551 mm) | 59.1 cm (591 mm) | 0.555 m² | DN100 (4" Tri-Clamp) | Small Batch cGMP Production |
| **AFD-100** | 100.0 L | 50.0 L | 2.20 kg/h | 65.4 cm (654 mm) | 70.1 cm (701 mm) | 0.778 m² | DN150 (6" Tri-Clamp) | Commercial High-Potency cGMP |
| **AFD-200** | 200.0 L | 100.0 L | 3.40 kg/h | 82.4 cm (824 mm) | 88.3 cm (883 mm) | 1.236 m² | DN150 (6" Tri-Clamp) | Commercial API Freeze-Drying |
| **AFD-500** | 500.0 L | 250.0 L | 7.20 kg/h | 111.8 cm (1118 mm) | 119.8 cm (1198 mm) | 2.276 m² | DN150 (6" Tri-Clamp) | High-Volume Active Bulk |
| **AFD-800** | 800.0 L | 400.0 L | 9.90 kg/h | 130.8 cm (1308 mm) | 140.2 cm (1402 mm) | 3.118 m² | DN200 (8" Tri-Clamp) | Large Scale Bulk Processing |
| **AFD-1000** | 1,000.0 L | 500.0 L | 11.40 kg/h | 140.8 cm (1408 mm) | 150.9 cm (1509 mm) | 3.618 m² | DN200 (8" Tri-Clamp) | High-Throughput Antibiotics |
| **AFD-1500** | 1,500.0 L | 750.0 L | 13.70 kg/h | 161.2 cm (1612 mm) | 172.8 cm (1728 mm) | 4.741 m² | DN250 (10" Flange) | Maximum Industrial Monoblock |

---

### 4.2 Governing Mechanical Sizing Formulation Matrix

This table summarizes the physical formulations implemented across the sizing engine:

| Module Identifier | Physical Principle | Governing Formula | Adjustable Inputs | Primary Output Metric | Verification Criterion |
| :--- | :--- | :--- | :--- | :--- | :--- |
| **MOD-01** | Cone Geometry | $h = \left[\frac{3V}{\pi \tan^2(\alpha)}\right]^{1/3}$ | Volume $V$ (L), Half-angle $\alpha$ ($20^\circ\text{--}35^\circ$) | Height $h$ (cm), Top Dia $D$ (cm) | Aspect ratio $h/D = 0.5 / \tan(\alpha)$ |
| **MOD-02** | Non-Linear Fill | $h_{\text{fill}} = h \cdot (f)^{1/3}$ | Batch fill fraction $f = V_{\text{batch}} / V_{\text{nom}}$ | Fill height $h_{\text{fill}}$, Freeboard % | $f = 0.5 \implies h_{\text{fill}} = 79.4\% \cdot h$ |
| **MOD-03** | Thermal Duty | $Q = \dot{m} \cdot \Delta H_s$ | Sublimation rate $\dot{m}$ (kg/h), $\Delta H_s = 2838\text{ kJ/kg}$ | Heat duty $Q$ (Watts) | Heat balance check |
| **MOD-04** | Area Adequacy | $A_{\text{req}} = \frac{Q}{U \cdot \Delta T}$ | Heat coeff $U$ (W/m²K), Jacket $\Delta T$ (°C) | Required area $A_{\text{req}}$ (m²) | $A_{\text{cone}} \ge A_{\text{req}}$ or add straight shell |
| **MOD-05** | Formed Head | $t = \frac{P \cdot L \cdot M}{2SE - 0.2P}$ | Pressure $P$ (barg), Stress $S$ (MPa), Joint $E$ | Minimum thickness $t$ (mm) | ASME Sec VIII Div 1 UG-32 |
| **MOD-06** | Annular Space | $V_{\text{jkt}} = \pi \bar{D} \cdot \delta \cdot L_s$ | Annular gap $\delta$ (default 50 mm), Wall $t_j$ | Holdup volume (L), Mass (kg) | Velocity $v \approx 1.5\text{ m/s}$ (LPM flow) |
| **MOD-07** | Elastic Buckling | Windenburg-Trilling Eq. | Thickness $t$ (mm), Equivalent $D_o$, Length $L$ | $P_{\text{cr}}$ (bar), Allowable $P_a$ (bar) | $P_a = P_{\text{cr}} / 3.0 \ge 1.013\text{ bar}$ |

---

### 4.3 Top Closure Head Types & ASME UG-32/UG-33 Compliance Matrix

The choice of top dish head impacts clean steam SIP containment, formed depth, cleanability, and vacuum collapse resistance:

| Head Type | Geometric Profile & Radii | ASME Stress Factor | Vacuum Collapse Equivalent | Forming Rise Depth $h_{\text{dish}}$ | Engineering Assessment & Selection Rule |
| :--- | :--- | :--- | :--- | :--- | :--- |
| **Torispherical (ASME F&D)** | Crown radius $L = D$, Knuckle radius $r = 0.06D$ | $M = \frac{3 + \sqrt{L/r}}{4} \approx 1.77$ | Equivalent sphere radius $R_o = L = D$ | $h \approx 0.169 \cdot D$ | **Recommended Practical Default**: Low profile, standard dishing dies, excellent cleanability, proven in sterile pharma. |
| **2:1 Semi-Ellipsoidal** | True 2:1 ellipse ($a = D/2, b = D/4$) | $K = \frac{1}{6}\left[2 + (D/2h)^2\right] = 1.0$ | Equivalent sphere radius $R_o \approx 0.90 \cdot D$ | $h = 0.250 \cdot D$ | **Maximum Pressure Efficiency**: Lowest required wall thickness, but higher formed rise adds vertical clearance demand. |
| **Flat Bolted Flange** | Flat circular plate with bolt circle | $C = 0.20$ to $0.33$ | Extreme bending moment under vacuum | $h = 0.000\text{ mm}$ (Flat) | **Restricted Envelope**: Unacceptable for diameters $> 300\text{ mm}$ under full vacuum due to excessive plate thickness ($> 25\text{ mm}$) and bolt load stresses. |

---

### 4.4 50 mm Annular Jacket Heat Transfer & Hydrodynamics Matrix

The annular space between the inner conical shell (product contact 316L) and the outer jacket shell (304L) is engineered with a **50 mm nominal radial gap** to achieve optimal hydrodynamic performance:

| Sizing Parameter | Engineering Value | Governing Physical Law | Engineering Rationale for 50 mm Annular Gap |
| :--- | :--- | :--- | :--- |
| **Nominal Radial Gap ($\delta$)** | **50 mm** (Adjustable 20 to 100 mm) | Geometric radial clearance | A 50 mm gap maintains ideal thermal fluid velocity ($1.2\text{ to }1.8\text{ m/s}$) at standard TCU pump flow rates (30 to 80 LPM), guaranteeing fully developed turbulent convection ($Re > 4,000$) without excessive pressure drops. |
| **Inner Cone OD** | $D_{\text{major}} + 2 \cdot t_{\text{shell}}$ ($+8\text{ mm}$) | Product contact wall | 4.0 mm to 6.0 mm 316L (EN 1.4404) electropolished to $Ra \le 0.2\,\mu\text{m}$. |
| **Jacket Inner Diameter (ID)** | $\text{Cone OD} + 2 \cdot \delta$ ($+100\text{ mm}$ for 50 mm gap) | Annular envelope | The jacket inner wall is spaced exactly 50 mm radially from the cone outer wall. |
| **Jacket Outer Diameter (OD)** | $\text{Jacket ID} + 2 \cdot t_{\text{jacket}}$ ($+6\text{ mm}$) | Outer pressure containment | 3.0 mm to 5.0 mm 304L (EN 1.4307) outer structural jacket shell. |
| **Thermal Fluid Holdup** | $V_{\text{jkt}} \approx A_{\text{lat}} \cdot \delta$ (Liters) | Annular fluid volume | For AFD-20 with $A_{\text{lat}} = 0.267\text{ m²}$ and 50 mm gap, fluid holdup is $\approx 13.4\text{ L}$ ($12.3\text{ kg}$ Syltherm XLT), ensuring rapid dynamic temperature response. |
| **Inlet / Outlet Orientation** | Bottom Apex (J1 In) $\rightarrow$ Top Flange (J2 Out) | Natural convection and venting | Fluid enters at the lowest apex cone elevation (J1) and discharges at the top flange ring (J2) to continuously purge entrained air bubbles and prevent vapor locking. |

---

## 5. CAD Export & Equipment Schedule JSON Schema

The tool generates machine-readable equipment nozzle schedules matching `cad_equipment_nozzle_schedule.json` for SolidWorks and Siemens NX parametric modeling:

```json
{
  "equipment_id": "AFD-V-101",
  "model_designation": "Hosokawa AFD-20",
  "nominal_volume_liters": 20.0,
  "max_batch_volume_liters": 10.0,
  "batch_volume_ratio": 0.50,
  "geometry": {
    "cone_half_angle_deg": 25.0,
    "top_inside_diameter_mm": 382.4,
    "bottom_apex_inside_diameter_mm": 100.0,
    "conical_shell_height_mm": 410.0,
    "dish_head_depth_mm": 64.6,
    "bottom_discharge_spool_height_mm": 60.0,
    "total_fabrication_height_mm": 534.6,
    "conical_lateral_area_m2": 0.267,
    "liquid_fill_height_50pct_mm": 325.5,
    "freeboard_height_mm": 84.5
  },
  "annular_jacket": {
    "annular_gap_mm": 50.0,
    "jacket_inside_diameter_mm": 490.4,
    "jacket_outside_diameter_mm": 496.4,
    "jacket_fluid_volume_liters": 13.35,
    "thermal_duty_watts": 631,
    "heat_transfer_area_required_m2": 0.315,
    "recommended_flow_rate_lpm": 25.0
  },
  "asme_bpvc_design_basis": {
    "code_standard": "ASME BPVC Section VIII Division 1 (UG-32 / UG-33)",
    "design_pressure_internal_barg": 3.0,
    "design_pressure_external_vacuum_bar": 1.013,
    "head_type": "Torispherical ASME F&D (M=1.77)",
    "calculated_minimum_head_thickness_mm": 1.84,
    "windenburg_trilling_allowable_external_bar": 5.42,
    "safety_factor": 3.0,
    "status": "PASSES_PRELIMINARY_BUCKLING"
  }
}
```

---

## 6. Architectural Role within the Research Lab

This sizing suite connects engineering theory from Chapter 05 (conical vessel mechanics and agitator kinematics) and Chapter 11 (thermodynamic sublimation balances and PV Elite code boundaries) directly into production artifacts:

1. **Chapter 13 (Engineering Drawings)**: Seeds dimensional elevations for general arrangement CAD drawings.
2. **Chapter 24 (CAD Nozzle Schedule)**: Feeds exact nozzle coordinates for process ports (N1 vacuum vapor, N2 product feed, N3 CIP sprayballs, N4 sampling port, N5 illumination sight glass, N6 vacuum release, N7 rupture disc, J1 jacket inlet, J2 jacket outlet, and bottom discharge port).
3. **P&ID Skid Automation**: Supplies fluid holdup volumes to the Temperature Control Unit (TCU) heat exchanger skid for cascade temperature loop tuning.

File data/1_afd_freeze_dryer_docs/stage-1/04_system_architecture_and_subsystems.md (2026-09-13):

# 04 — System Architecture & Subsystem Breakdown

See `diagrams/system_block_diagram.png` for an original block diagram of the full system described below.

## Top-level subsystem map

This structure follows Hosokawa's own named subsystem list (from the AFD page and the general drying-systems page) combined with the mechanical detail from the two patents (file 03), organized the way you'd actually plan a build:

```
                       ┌─────────────────────────┐
                       │   Control System (PLC/   │
                       │   HMI, 21 CFR Part 11)   │
                       └────────────┬─────────────┘
                                    │ I/O
        ┌────────────┬─────────────┼─────────────┬─────────────┐
        │             │             │             │             │
   ┌────▼───┐   ┌─────▼─────┐ ┌────▼────┐  ┌─────▼─────┐ ┌─────▼──────┐
   │  TCU   │   │  Vessel/  │ │ Vacuum  │  │  Material  │ │ CIP/SIP    │
   │ (heat/ │──▶│  Chamber  │▶│  Path   │─▶│ Collector  │▶│  Skid      │
   │  cool) │   │ + Agitator│ │ (valve, │  │ + Vacuum   │ │            │
   └────────┘   └─────┬─────┘ │ bypass) │  │   Pump     │ └────────────┘
                       │       └─────────┘  └────────────┘
                 ┌─────▼─────┐
                 │  Bottom   │
                 │ Discharge │
                 │  Valve    │──▶ Product Collection Canister
                 └───────────┘

   Utility Management Skid: interfaces all of the above to
   plant electricity, compressed air/nitrogen, process water,
   steam (if SIP), chilled water/glycol, and drains.
```

## Subsystem list, with what each one does and where it's covered in this package

| # | Subsystem | Function | Covered in |
|---|---|---|---|
| 1 | **Lyophilisation vessel/chamber** | Downward-conical, jacketed pressure/vacuum vessel that holds the product through freeze + dry | File 05 |
| 2 | **Agitator & drive** | Orbiting screw/paddle/ribbon; scrapes vessel wall; magnetic or sealed drive | File 05 |
| 3 | **Vessel jacket & TCU** | Double-jacketed wall; external skid circulates heat-transfer fluid for both cooling (freeze) and heating (dry) | File 06 |
| 4 | **Refrigeration system** | Supplies cold duty to TCU and (in classic designs) the condenser | File 06 |
| 5 | **Vacuum system** | Pump train, gauges, isolation valves, piping — pulls and holds process vacuum | File 06 |
| 6 | **Material collector / dust filter** | External filter housing in the vacuum line; recovers dry powder from the vapor stream; AFD-specific valve/bypass arrangement | File 06 |
| 7 | **Bottom discharge valve** | Ball-segment (or equivalent) valve for full product dump at end of cycle | File 05 |
| 8 | **CIP system** | Spray balls/rotary nozzles, chemical dosing, water rinse cycles | File 07 |
| 9 | **SIP system (optional)** | Clean steam generation/distribution for in-place sterilization | File 07 |
| 10 | **Seals, gaskets, insulation** | Elastomer door/lid seals, agitator shaft seal or magnetic coupling, external insulation jacket | File 07 |
| 11 | **Instrumentation** | Pressure gauges (Pirani + capacitance manometer), temperature (product/jacket/condenser), level, torque | File 08 |
| 12 | **Valves & piping** | Sanitary process valves, vacuum isolation valves, utility piping | File 08 |
| 13 | **Control system (PLC/HMI/SCADA)** | Recipe execution, data logging, alarms, 21 CFR Part 11 electronic records | File 08 |
| 14 | **Electrical system** | Motor drives, control power, ATEX-rated equipment in dust zones | File 08 |
| 15 | **Structural frame** | Skid/frame supporting the vessel, drive, and services; access platform if tall | File 08 |
| 16 | **Utility Management Skid** | Single interface point to plant electricity, compressed air/N₂, process water, steam, chilled water, drains | File 08 |
| 17 | **Safety systems** | Vacuum/pressure relief, interlocks, ATEX-rated components in dust zones, e-stop circuits | File 09 |

## How the process cycle exercises each subsystem

See `diagrams/freeze_drying_cycle_profile.png` for an original time/temperature/pressure chart of a representative cycle.

1. **Charge** — product loaded into vessel (top port, per patent drawings), lid closed and clamped/sealed.
2. **Pre-cool / freeze** — TCU circulates cold fluid through jacket; agitator running slowly; vessel at or near atmospheric pressure initially, per NL2026893B1's description ("temperature within the freeze-drying chamber is lowered to a temperature close to and above the freezing temperature... by introducing a heat-exchanging medium into the double-jacketed vessel wall"), then vacuum is drawn to induce final freezing.
3. **Vacuum draw / vacuum-induced freezing** — vacuum system pulls chamber down; as pressure drops, product temperature drops further (evaporative/flash cooling) until freezing is complete and the mass has broken into free-flowing granular ice, assisted by continuous agitation.
4. **Primary drying** — jacket temperature raised under TCU control while vacuum is held; agitator continues at low speed; sublimed vapor flows out through the material-collector valve path (open early, closed/bypass later per NL2026893B1); dried powder accumulates in the collector.
5. **Secondary drying** — jacket temperature raised further; vacuum held; remaining bound moisture desorbed.
6. **End-of-cycle blowback & post-blend** — filter purge dislodges collected powder into the heated recipient; valve reopens to return collected material to vessel for post-blending into one uniform batch (per NL2026893B1).
7. **Vacuum release** — controlled break to atmosphere (via sterile air/N₂ if aseptic).
8. **Discharge** — bottom valve opens; product drops to collection canister.
9. **CIP (and SIP if required)** — automated wash/sterilize cycle before next batch.

## Why this maps well to a workshop build

Every one of the 17 subsystems above is either (a) a mechanical/plumbing assembly a well-equipped workshop can fabricate or adapt commercial components for, or (b) a component you should simply buy (vacuum pump, PLC, sensors, seals). File 10 draws that make/buy line item-by-item; file 12 turns it into an actual BOM.

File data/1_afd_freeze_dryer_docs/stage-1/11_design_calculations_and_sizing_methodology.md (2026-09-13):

# 11 — Design Calculations & Sizing Methodology

All worked numbers below use a **representative 10 kg batch (≈10 L) of a 90% water solution, in a nominal ~20 L vessel** — chosen because it lines up with a size Hosokawa itself publishes indicative performance for on the AFD page (their "20 L model" is quoted with a 10 L max batch volume and an indicative sublimation capacity of 0.8 kg/h), letting us **cross-check a first-principles calculation against Hosokawa's own published figure** without needing any proprietary data. Every number below is illustrative engineering methodology, not a specification for your build — rerun these with your own batch size, product properties, and measured (not assumed) heat-transfer coefficients once you have a prototype to test.

## 1. Sublimation rate ↔ heat duty (cross-checked against Hosokawa's published figure)

The core relationship (file 02 §3):
```
Q = (dm/dt) × ΔHs
```
`ΔHs` (latent heat of sublimation of ice) ≈ 2,838 kJ/kg.

Plugging in **Hosokawa's own published 0.8 kg/h** for the 20 L model:
```
dm/dt = 0.8 kg/h = 2.222×10⁻⁴ kg/s
Q = 2.222×10⁻⁴ × 2,838,000 J/kg ≈ 631 W
```
**A ~630 W jacket heat duty to sustain 0.8 kg/h sublimation is a small, entirely buildable number** for a 20 L-class unit — well within a single-phase electric heater or a modest hot/cold TCU circuit. This is a useful sanity check: if your own design's required heat duty for a similar batch size comes out wildly different (say, tens of kW), that's a strong signal to re-examine your assumptions before building anything.

**Time to sublime the batch's water content**, at that rate: for 9 kg of water (90% of a 10 kg batch) at 0.8 kg/h, primary drying takes **≈11.25 h** — consistent with the "hours to days" range generic literature gives for primary drying, and with Hosokawa's own 2003 patent's "10–100 hours for a 50 L charge" figure (a larger charge, so a longer time, is directionally consistent).

## 2. Required jacket heat-transfer area

```
Q = U × A × ΔT   →   A = Q / (U × ΔT)
```
- `U` = overall heat transfer coefficient, jacket wall → agitated product. **This is genuinely product- and design-specific and cannot be looked up reliably** — it depends on wall material/thickness, agitation intensity, particle size, and chamber pressure (gas-phase conduction across any micro-gaps is pressure-dependent, same physics as file 02's vial-heat-transfer-coefficient discussion). A reasonable **first-pass planning range for an actively agitated, direct-contact granular bed is roughly 50–200 W/m²·K** — meaningfully better than the static-vial gas-gap coefficients reported in the Pikal-model literature (which are often only single digits to tens of W/m²·K, precisely *because* a static vial's heat path crosses a poorly-conducting gas gap that agitation is specifically designed to eliminate), but this must be measured on your own prototype, not assumed for a final design.
- `ΔT` = jacket-wall-to-product temperature differential; **10–30 °C** is a reasonable planning range, consistent with typical primary-drying shelf-to-product differentials reported in the shelf-freeze-dryer literature.

At `Q ≈ 631 W`:

| Assumed U (W/m²K) | Required area for ΔT = 20 °C |
|---|---|
| 50 | 0.63 m² |
| 100 | 0.32 m² |
| 150 | 0.21 m² |
| 200 | 0.16 m² |

A vessel wall area in the 0.15–0.65 m² range is entirely consistent with the wetted internal-cone surface area of a vessel sized to hold a 10–20 L batch — another sanity-check pass. **Build in adjustable jacket-fluid temperature control (via the TCU) so you can tune actual ΔT once you've measured your real U empirically**, rather than trying to nail this on paper alone.

## 3. Freezing-stage refrigeration load

Three sequential heat-removal steps for a 10 kg batch (90% water), cooling from +20 °C ambient to a −30 °C frozen mass (an illustrative target inside Hosokawa's patent-disclosed −55 °C to −15 °C post-freeze range):

```
Q1 (cool liquid, 20 °C → 0 °C)   = m × cp_liquid × ΔT  = 10 kg × 4.2 kJ/kg·K × 20 K   = 840 kJ
Q2 (freeze the water content)    = m_water × ΔHf        = 9 kg × 334 kJ/kg             = 3,006 kJ
Q3 (cool frozen mass, 0 → −30°C) = m × cp_ice × ΔT       = 10 kg × 2.1 kJ/kg·K × 30 K   = 630 kJ
                                                            ─────────────────────────────
                                                            Total ≈ 4,476 kJ (4.48 MJ)
```

Average refrigeration duty depends on how fast you want to complete freezing — which is itself bounded by Hosokawa's own disclosed **0.1–10 °C/min optimum freezing rate**:

| Freezing time | Implied cooling rate (50 °C swing) | Avg. refrigeration duty |
|---|---|---|
| 2 h | 0.42 °C/min | 0.62 kW |
| 1 h | 0.83 °C/min | 1.24 kW |
| 0.5 h | 1.67 °C/min | 2.49 kW |

All three sit comfortably inside Hosokawa's disclosed 0.1–10 °C/min range, and all three are modest, workshop-buildable refrigeration duties (roughly "large chest freezer" to "small commercial chiller" scale) — **before** accounting for jacket/ambient losses and TCU inefficiency, for which a **1.5–2× capacity margin over the calculated average duty** is standard engineering practice, and before accounting for the *separate* condenser/material-collector refrigeration duty (file 06 §2), which must remove the same latent heat again when the sublimed vapor re-condenses/freezes downstream.

## 4. Vacuum pump-down time (empty-vessel, first-pass estimate)

The standard exponential pump-down relationship for evacuating a fixed volume with a pump of constant volumetric speed (ignoring outgassing/vapor load — a valid approximation only for the initial, dry evacuation before ice starts subliming):
```
t = (V / S) × ln(P1 / P2)
```
For a 20 L (0.02 m³) free vessel volume, pumping from atmospheric (1,013 mbar) down to 1 mbar:

| Pump speed S | Pump-down time |
|---|---|
| 5 m³/h | ~100 s |
| 10 m³/h | ~50 s |
| 20 m³/h | ~25 s |
| 50 m³/h | ~10 s |

**This is only the "dry" evacuation time.** Once the product starts giving off water vapor (during freezing induction and especially during primary drying), the pump must additionally handle the ongoing sublimation vapor load — at the 0.8 kg/h sublimation rate above, that's roughly 0.22 g/s of water vapor, which at low pressure occupies a very large volumetric flow (ideal gas law: at 1 mbar and −20°C, 0.22 g/s of water vapor is on the order of several hundred L/s of volumetric flow) — this is the actual reason freeze-dryer vacuum pumps are specified against **vapor handling capacity at the operating pressure**, not against empty-chamber pump-down speed. Pump selection should be driven by this sublimation vapor load calculation (and by the condenser's job of removing most of that vapor as ice before it ever reaches the pump — file 06 §4), with the empty-vessel pump-down number used only as a secondary check on how quickly you can get the system down to the freezing-induction pressure at the start of each batch.

## 5. Agitator power — an honest "you must measure this" section

Unlike the calculations above, agitator torque/power for a granular, partially-frozen bed **cannot be reliably predicted from first principles** without either detailed granular-flow modeling or empirical testing — the resistance depends on particle size, degree of caking, fill level, and the specific mixing-element geometry you build. What can be stated with confidence:

- Hosokawa's own patent explicitly notes that **because freeze-drying is slow, only gentle mixing is needed** — this is not a high-power, high-shear mixing duty like a chemical reactor.
- For scale intuition only (not a sizing method): Hosokawa's general-purpose Nauta mixer line uses a **2.2 kW motor at 500 L** (file 03 §3) for full-intensity powder mixing duty — a 20 L freeze-dryer vessel, running at a much gentler speed for a much gentler duty, will need dramatically less, plausibly in the tens-to-low-hundreds-of-watts range, but **this should be confirmed empirically**: specify a variable-frequency drive with generous headroom over your best estimate, instrument the drive for torque/current (file 08 §1), and let the real, measured load — including the worst case, which is likely mid-freeze when the mass is partially solidified and most resistant to being moved — set your final motor selection rather than a paper calculation.

## 6. External-pressure vessel thickness — method reference

For the vessel and jacket wall thickness under full external vacuum, use the standard **ASME Section VIII Division 1, UG-28 procedure** (file 05 §5): assume a trial thickness, compute the shell's `L/Do` and `Do/t` ratios, read the geometry/material factor from the Code's charts (or the equivalent numerical method in the Code's non-mandatory appendices), and verify the resulting allowable external pressure exceeds your design case (full vacuum, i.e., ~1 atm/1.013 bar external differential, plus any additional margin your jurisdiction's code requires) with the Code-mandated safety factor against theoretical elastic collapse. This procedure is iterative (thickness assumed → checked → revised) and is most practically run using the standard external-pressure charts/software your fabricator or design engineer already uses, rather than hand-calculated from scratch — flagged here as a methodology pointer, not repeated in full, since it is standard, already-mastered territory for anyone with ASME Section VIII pressure-vessel design background.

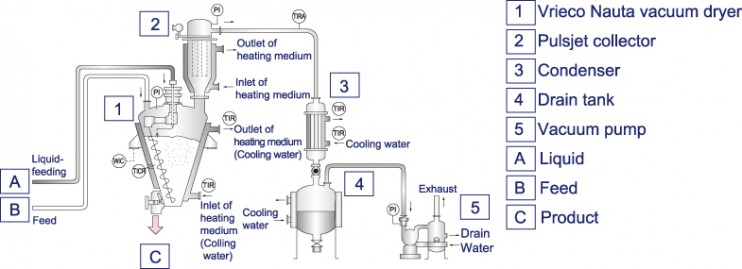
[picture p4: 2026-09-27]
public/photos/vrieco_nauta_vacuum_dryer_condenser_draintank_schematic.jpg

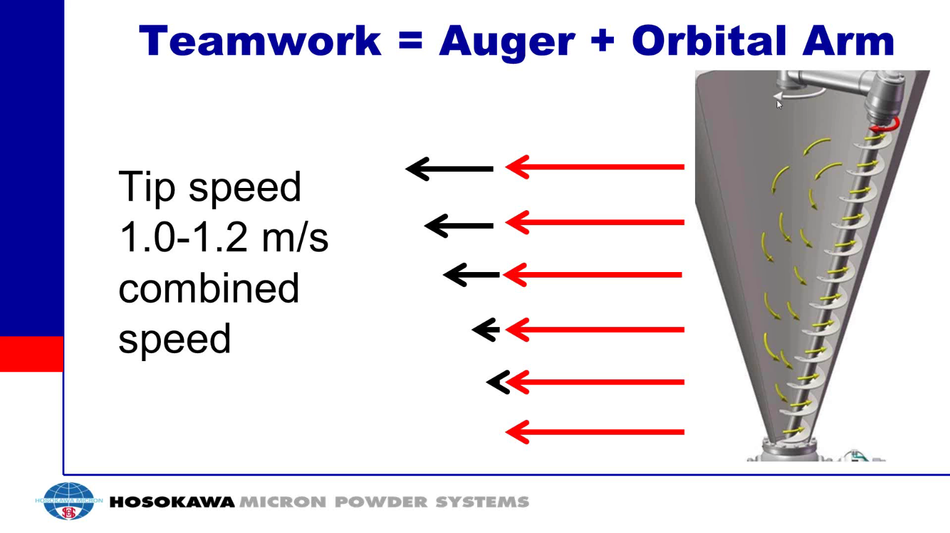
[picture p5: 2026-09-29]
public/photos/webinar_captures/nauta_auger_orbit_arm_tip_speed_kinematics.png

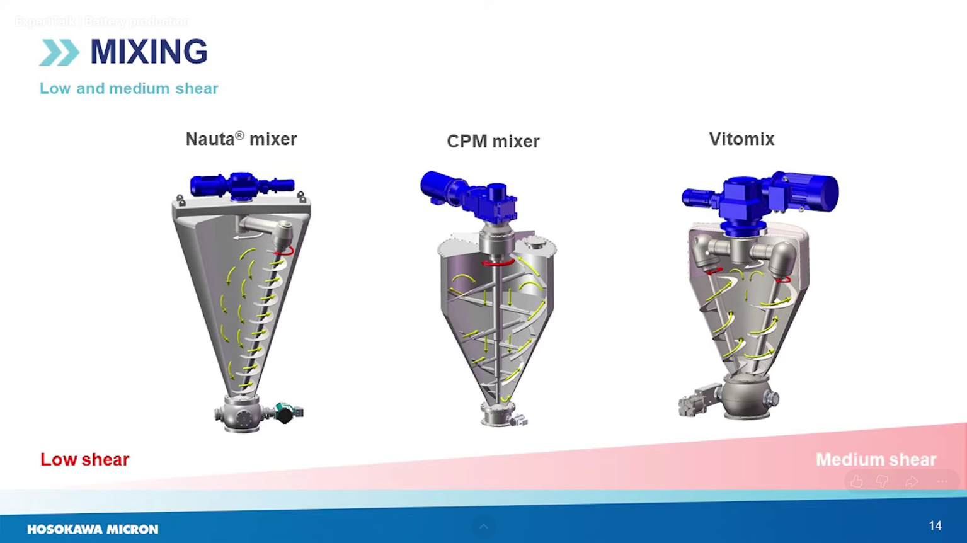
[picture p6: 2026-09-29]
public/photos/webinar_captures/hosokawa_experttalk_mixing_shear_intensity_spectrum.png

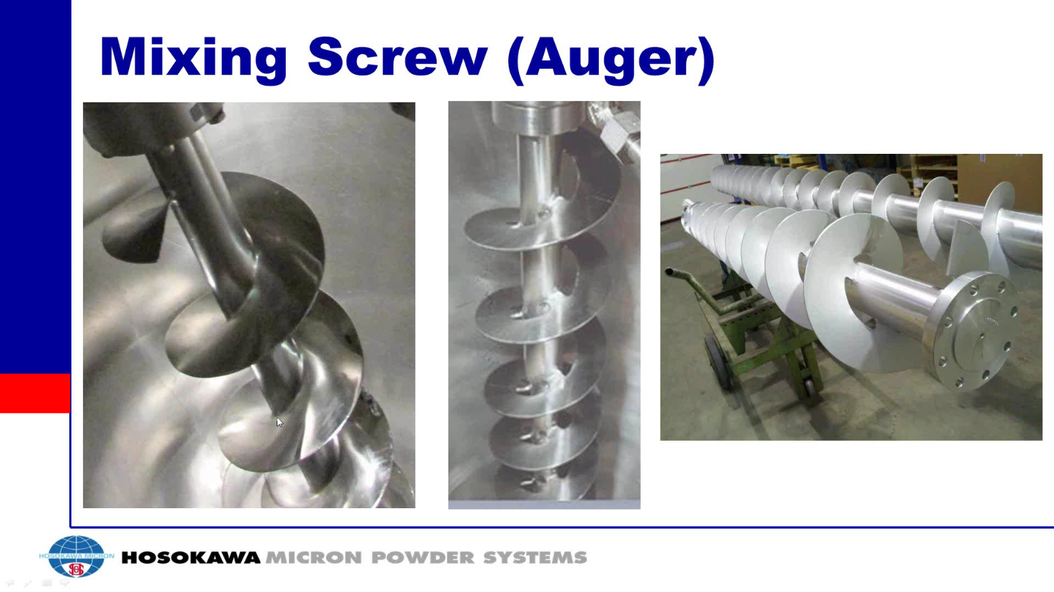
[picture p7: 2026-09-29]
public/photos/webinar_captures/nauta_mixing_screw_auger_flight_design.png

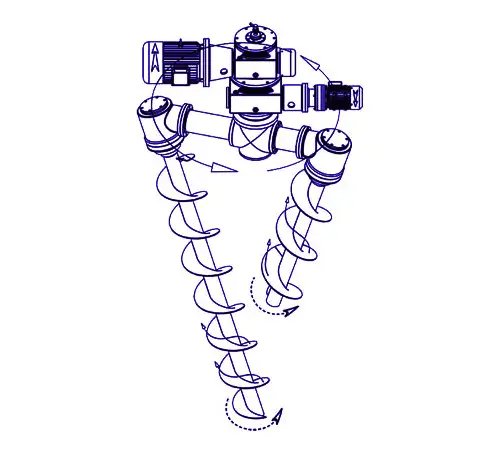
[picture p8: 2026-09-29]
public/photos/nauta_vertical_cone_screw_blender_overview.webp

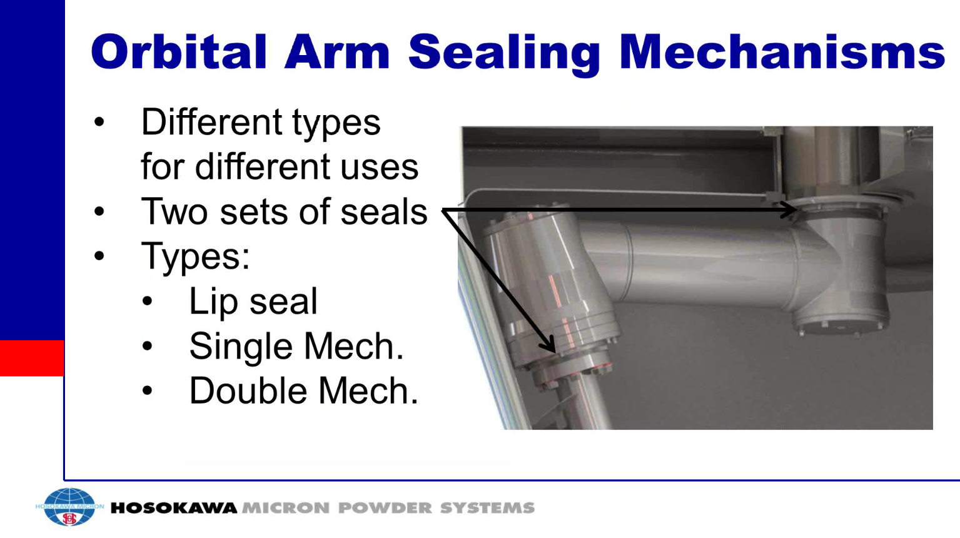
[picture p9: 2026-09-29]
public/photos/webinar_captures/nauta_orbital_arm_sealing_mechanisms_lip_mechanical.png

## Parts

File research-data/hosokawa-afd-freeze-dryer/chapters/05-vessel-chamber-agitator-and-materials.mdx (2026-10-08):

---
title: "Vessel Conical Chamber, Agitator & Drive Mechanism"
chapterNumber: "05"
slug: "05-vessel-chamber-agitator-and-materials"
act: "Mechanical & Vessel Engineering"
actId: "act-2"
readTime: "12 min read"
simulators: ['VesselCrossSection3D']
---

# 05 — Vessel Conical Chamber, Agitator & Drive Mechanism

Hosokawa Active Freeze Dryer (AFD) Isolated Machine Architecture

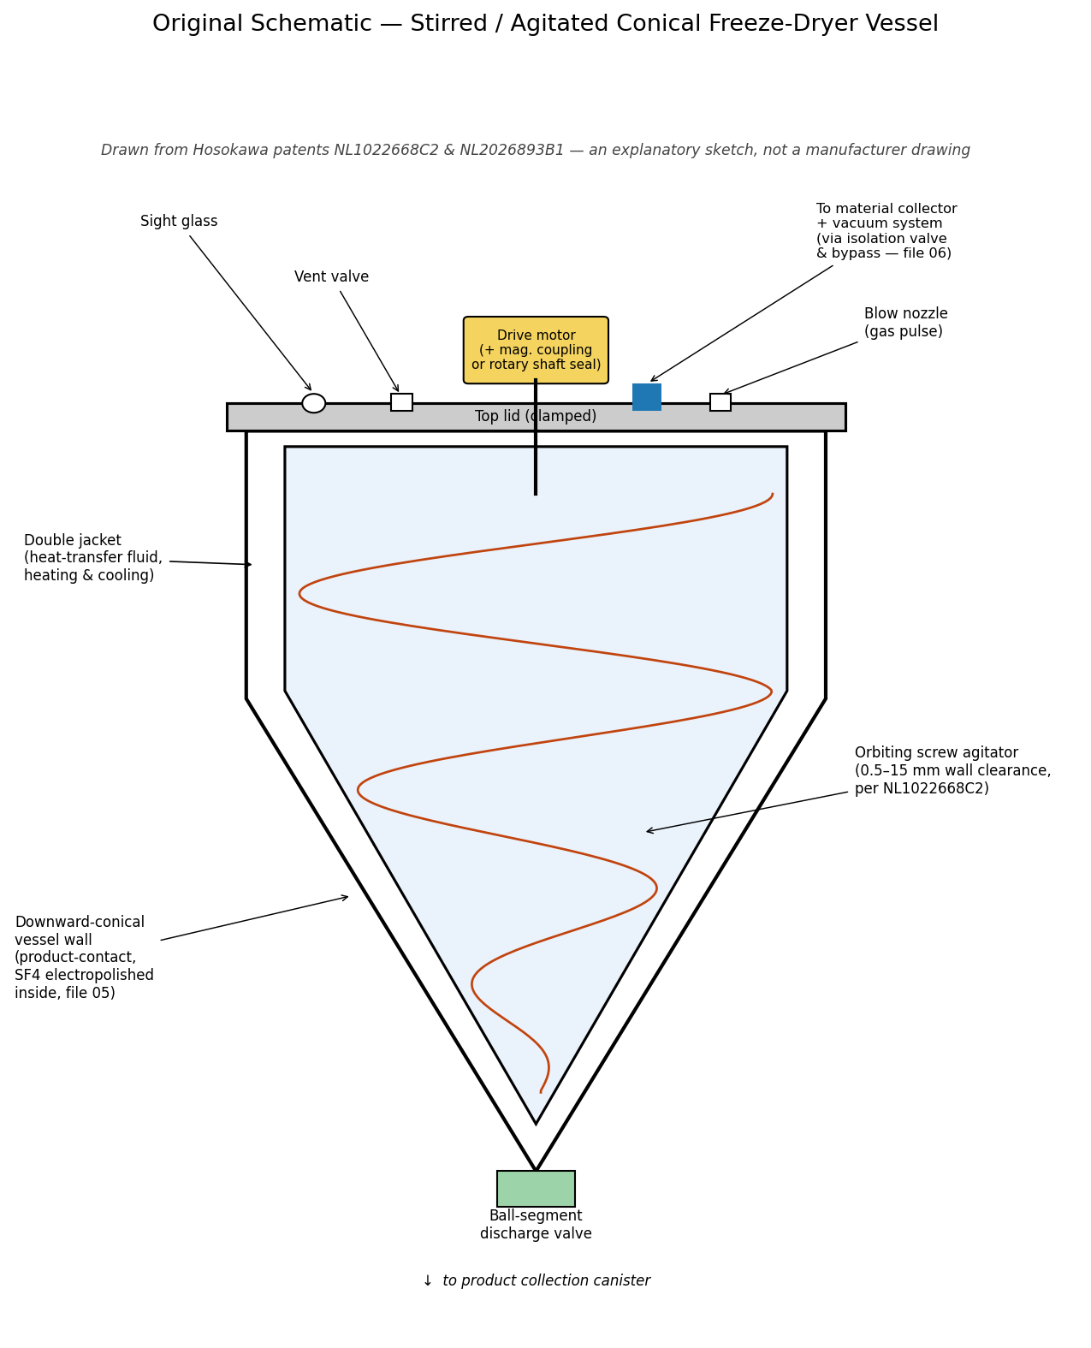
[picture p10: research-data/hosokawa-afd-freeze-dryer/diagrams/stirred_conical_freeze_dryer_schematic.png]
Stirred Conical Freeze Dryer Schematic


Hosokawa Nauta Conical Screw Blender Vessel Overview

Pilot-Scale Mobile Conical Agitated Vacuum Dryer Unit with Sanitary Sight Glass & Ball-Segment Valve

## 1. Vessel geometry

Conical Vessel Volume & Aspect Ratio Formulas (V = πr²h/3)

Nauta Mixer Capacity & Working Volume Range (10% to 100%)

Nauta Conical Mixer Pharmaceutical Stainless Steel Vessel Construction

Nauta 5-Liter Laboratory Benchtop Pilot Vacuum Dryer

Hosokawa Nauta Mobile Pilot Test Skid Model VDC-08 with Integrated Condenser

Nauta Vacuum Dryer Model 10-VDC Cleanroom Pilot Skid

Nauta Model 10-VDC Pilot Unit Instrumentation & Assembly Detail

Nauta Vacuum Dryer Model 35-HDC with Internal Heated Agitator Screw

Nauta Vacuum Dryer Model 60-VDC Full Commercial Production Plant Installation

Per NL1022668C2 and NL2026893B1 (file 03), the vessel features:
- **Downward-conical geometry** (cone point at bottom), optionally with a short cylindrical section at the top near the lid to give room for the drive, seals, and top-mounted nozzles. The patent explicitly notes this is common on classical conical mixers.
- A cylindrical vessel with only a conical bottom section is an acceptable, more space-efficient variant. The cylindrical-to-conical proportion must preserve mixing action.
- **Double-jacketed wall**: two concentric compartments (per NL2026893B1 Figure 1B) around the vessel wall. Each carries heat-exchange media, allowing wall cooling during freezing and heating during drying without fluid cross-contamination.
- **Open top**, closed by a top lid fixed with clamping screws. Quick-release clamp closures provide sanitary equivalents in workshop builds.
- **Open bottom**, closed by a releasable outlet (ball-segment valve) for complete discharge.

Hosokawa does not publish vessel diameter, height, wall thickness, or exact cone angle for the AFD. Treat vessel geometry as a design variable you calculate based on your target batch volume.

## 1a. Sizing the vessel: working-volume ratio, cone angle, and closures

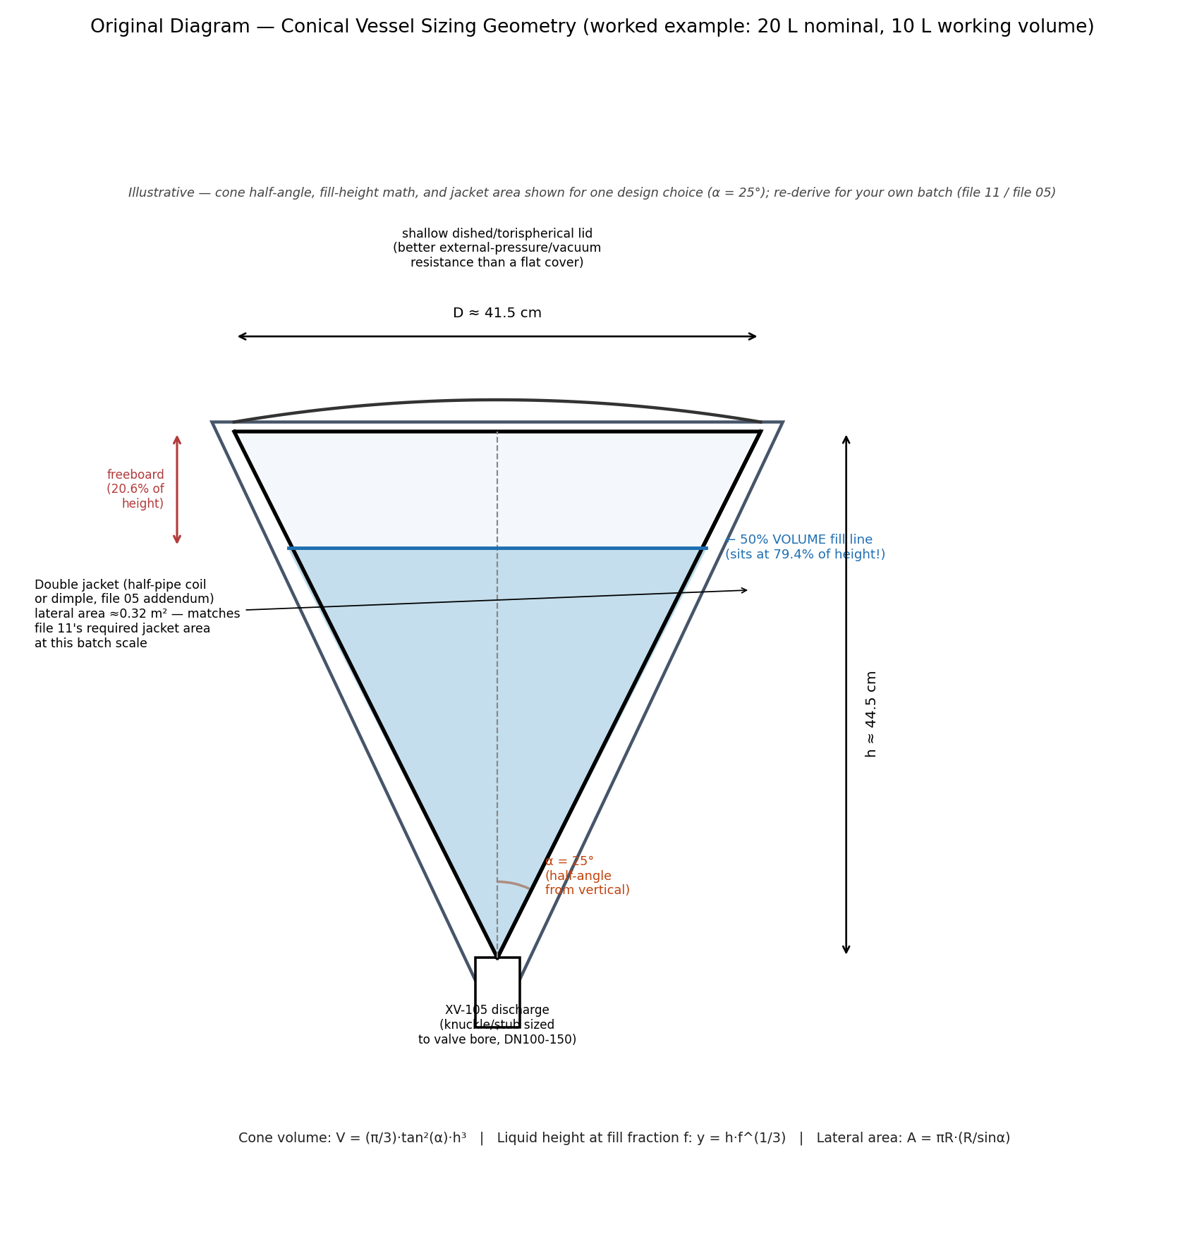
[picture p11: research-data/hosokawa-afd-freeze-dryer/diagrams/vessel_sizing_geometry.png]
Vessel Sizing Geometry and Working Volume Relationship


### The working-volume ratio is published data: 50%, not 80%

Hosokawa publishes a table of 10 nominal models from 1 L to 1,500 L. Every model specifies a maximum batch volume of exactly 50% nominal vessel volume:
- 1 L vessel holds 0.5 L batch.
- 20 L vessel holds 10 L batch.
- 100 L vessel holds 50 L batch.
- 1,500 L vessel holds 750 L batch.

This constant holds across two orders of magnitude. Use 50% as your design basis.

The AFD requires more headroom than an ordinary liquid tank for four physical reasons:
1. **The orbiting agitator needs headspace.** A Nauta-style screw lifts and folds product along the wall. Filling beyond 50% restricts product turnover at the top.
2. **The frozen bed occupies more volume than liquid.** Ice is 9% less dense than water. In addition, agitated freezing breaks the mass into loose, snow-like granules. Loose powder beds contain substantial gas voids. Total bulking frequently exceeds 30% to 50%. A 50% fill leaves a 2x volume safety factor. An 80% fill leaves only 1.25x margin.
3. **Vapor needs an unobstructed disengagement zone.** Sublimed water vapor travels from the bed to the top nozzle. Ample headspace reduces vapor superficial velocity, preventing fine powder carryover into the dust collector.
4. **Aqueous solutions foam under vacuum pull.** Dissolved gases boil out during initial evacuation, raising the liquid surface temporarily.

### Volume fraction versus height fraction in a cone

In a downward cone, volume scales with the cube of liquid height:

$$h_{\text{fill}} = h_{\text{total}} \cdot \left(\frac{V_{\text{fill}}}{V_{\text{nominal}}}\right)^{1/3}$$

| Volume Fill (%) | Liquid Height (% of Total) | Freeboard Height (%) |
|---|---|---|
| 30% | 66.9% | 33.1% |
| 40% | 73.7% | 26.3% |
| **50%** | **79.4%** | **20.6%** |
| 60% | 84.3% | 15.7% |
| 70% | 88.8% | 11.2% |
| 80% | 92.8% | 7.2% |

At 50% volume fill, liquid reaches 79.4% of total cone height. You retain only 20.6% of vertical height as freeboard. At 80% volume fill, freeboard collapses to 7.2% of height.

To add physical headroom without widening the floor footprint, add a short cylindrical straight-side above the cone. Cylinder volume scales linearly with height, providing freeboard more efficiently than cone elongation.

### Selecting cone half-angle

Hosokawa Nauta mixer dimensions indicate half-angles between 20° and 22.5° from vertical. Practical builds operate between 20° and 35°:
- **Steeper cone (20°)**: Taller vessel with smaller top diameter. Improves gravity powder discharge. Maximizes external pressure buckling resistance by reducing unsupported shell span.
- **Shallower cone (35°)**: Shorter overall height. Larger top diameter increases buckling risk under vacuum. Leaves larger residual powder heels at the apex.

### Worked sizing example: 10 L working volume (20 L nominal vessel)

For a 10 L liquid batch, size a 20 L nominal vessel. Select a 25° half-angle ($\alpha = 25^\circ$):

$$V_{\text{cone}} = \frac{\pi}{3} \cdot \tan^2(\alpha) \cdot h^3 \implies h = \left[\frac{3 \cdot V}{\pi \cdot \tan^2(\alpha)}\right]^{1/3}$$

For $V = 20{,}000\text{ cm}^3$ and $\alpha = 25^\circ$:
- Height $h \approx 44.5\text{ cm}$.
- Top internal diameter $D = 2 \cdot h \cdot \tan(\alpha) \approx 41.5\text{ cm}$.
- Liquid level at 50% fill ($0.7937 \cdot h$) sits at $35.3\text{ cm}$ above apex. Freeboard equals $9.2\text{ cm}$.
- Cone lateral surface area:

$$A_{\text{lat}} = \frac{\pi \cdot R^2}{\sin(\alpha)} = \frac{\pi \cdot (20.75)^2}{\sin(25^\circ)} \approx 0.32\text{ m}^2$$

This $0.32\text{ m}^2$ lateral area matches the required jacket heat-transfer area calculated independently in Chapter 11 ($0.32\text{ m}^2$ at $U = 100\text{ W/m}^2\text{K}$ and $\Delta T = 20\text{ K}$).

## 1b. Top closure and bottom apex: head geometry selection

Mixer Top Cover Dished Head & Flanged Nozzle Positions

Vertical Cone Screw Blender Sanitary Inspection Port & Sight Glass Assembly

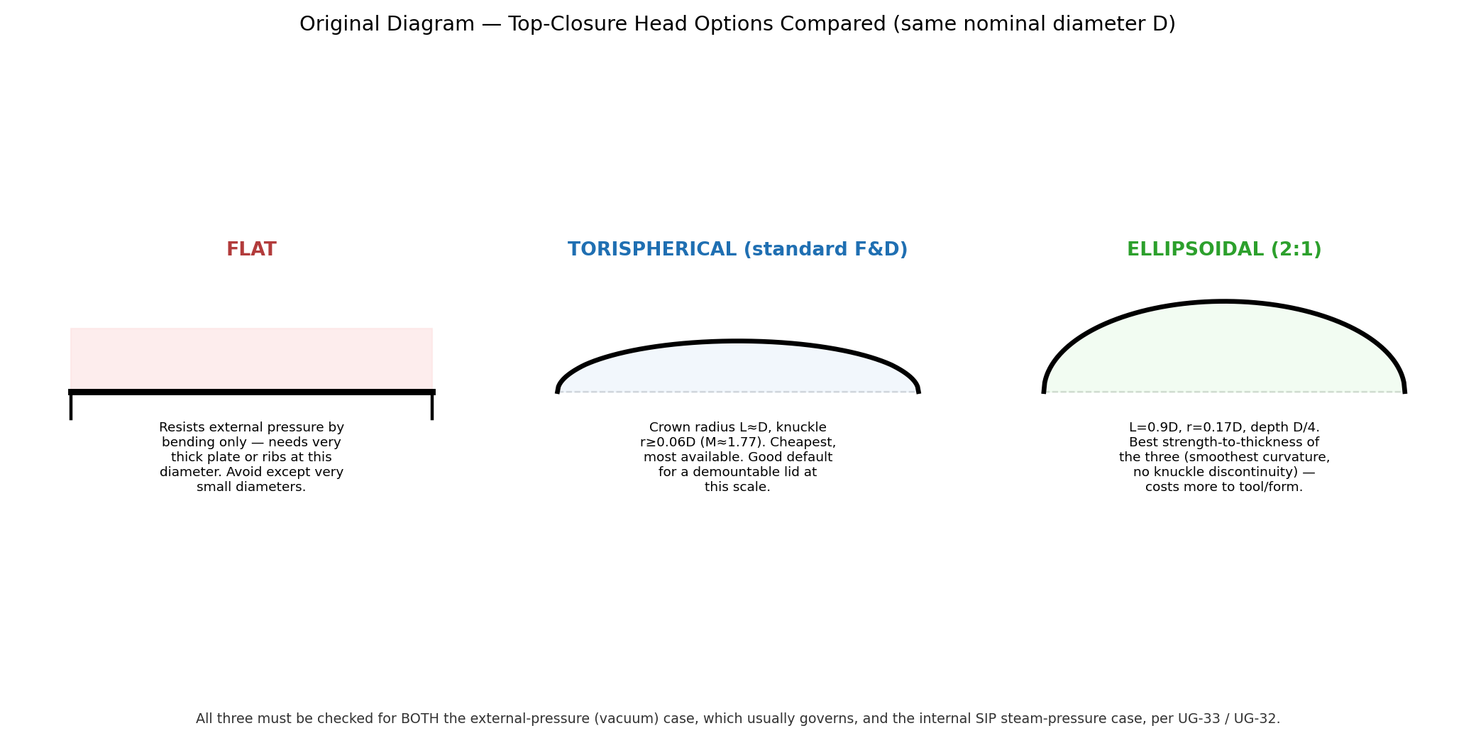
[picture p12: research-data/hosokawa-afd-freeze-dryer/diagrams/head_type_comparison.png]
Comparison of Vessel Head Profiles: Flat vs Torispherical vs Ellipsoidal


### Comparing head types for vacuum and pressure service

| Head Type | Geometry Ratios | External Pressure (Vacuum) Behavior | Application Recommendation |
|---|---|---|---|
| **Flat Cover** | Simple plate | Resists load by bending only. Requires thick, heavy plate as diameter grows. | Avoid on vessels above 200 mm diameter. Impractical thickness under vacuum. |
| **Torispherical (ASME F&D)** | Crown radius $L \approx D$, knuckle $r \ge 0.06D$. Knuckle factor $M = \frac{3+\sqrt{L/r}}{4} \approx 1.77$. | Equivalent sphere radius $R_o = L \approx D$ under ASME UG-33. | **Practical default.** Readily stocked, economical to form. Knuckle thickness penalty is minimal at modest diameters. |
| **2:1 Ellipsoidal** | Crown radius $L = 0.9D$, knuckle $r = 0.17D$. Depth equals $D/4$. | Equivalent sphere radius $R_o = 0.9D$ under ASME UG-33. Continuous curvature eliminates stress concentrations. | Premium upgrade. Provides lower wall thickness and higher buckling resistance. Tooling costs are higher. |

### Dual load case verification

You must evaluate two distinct load cases:
1. **Full vacuum (external pressure, ASME UG-33)**: Governs baseline wall thickness. Evaluated using the equivalent sphere radius $R_o$.
2. **Steam sterilization (internal pressure, ASME UG-32)**: Clean steam at 2 to 4 barg.
   - For 2:1 Ellipsoidal: $t = \frac{P \cdot D \cdot K}{2 \cdot S \cdot E - 0.2 \cdot P}$ with $K = 1.0$.
   - For Torispherical: $t = \frac{P \cdot L \cdot M}{2 \cdot S \cdot E - 0.2 \cdot P}$ with $M \approx 1.77$.

Run both checks. External vacuum governs minimum thickness in almost all conical freeze dryers.

### Bottom apex transition

The conical shell must not terminate in a sharp point. Truncate the apex into a cylindrical nozzle stub sized for your bottom discharge valve (DN100 to DN150, per file 24). Form a knuckle radius at the cone-to-cylinder transition to mitigate bending stresses per ASME Section VIII Appendix 1.

## 2. Fittings on the lid

Fittings on the top cover include:
- Vacuum vapor outlet port leading to the material collector. Features a sanitary clamp flange and interlock proximity sensor.
- Flanged sight glass port with LED illuminator for process viewing.
- Nitrogen vent valve port for controlled atmosphere release.
- Clean gas blow nozzles aimed at chamber walls for powder discharge assist.
- Rotary spray devices for automated CIP cleaning.

## 3. Agitator Kinematics & Mixing Dynamics

::youtube[https://www.youtube.com/watch?v=oNc7KjdoQys]{title="Laboratory Mixer for Dry Powders - Hosokawa Micron Labomixer" channel="HosokawaMicron" duration="3:08" context="Chapter 05 Agitator Kinematics" caption="Demonstration of orbiting screw rotation, convective lifting, and powder cascade in a conical mixer chamber with zero dead space."}

Teamwork: Auger + Orbital Arm Combined Tip Speed (1.0-1.2 m/s)

Auger vs Orbital Arm 10:1 Power Dissipation Ratio

Vrieco-Nauta MFC-44 & ON 300 Drive Gearbox Layout

Orbital Arm Drive Transmission: Gear vs Belt Train

Nauta Model 56051 Sanitary Shrouded Drive Motor Unit

Twin-Screw Conical Mixer Orbital Drive Top Transmission View

Vertical Cone Screw Blender Auger Drive Head Bearing Bracket

Auger Flight Geometry, Core Shaft, & Screw Lead Angles

Supported Screw Pintle Bearing vs Cantilevered Hygienic Design

Hosokawa Nauta Three-Action Conical Mixing Dynamics

Nauta Agitator Screw, Flush Ball Valve & Wall Clearance Anatomy

### Three-Action Triad Kinematics
1. **Vertical Wall Conveyance**: High-speed auger rotation lifts product upwards in a thin spiral layer along the heated vessel wall.
2. **$360^\circ$ Orbital Precession**: The top orbit arm sweeps the auger along the conical periphery at 1.0–2.5 RPM, distributing material circumferentially.
3. **Core Gravitational Cascade**: Lifted product discharges off the top flighting into the vessel center, cascading down the central void to the apex.

### Agitator Comparison: Screw vs. Ribocone Ribbons
- **Cantilevered Conical Screw (Nauta)**: Optimal for low-shear powder turnover and freeze drying. Operates with low Froude numbers ($Fr = \frac{\omega^2 r}{g} < 0.1$), preserving fragile crystals, living bacterial cultures, and delicate API matrices without attrition.
- **Single Ribbon / Double Ribbon (Ribocone)**: Central spiral ribbon sweep suited for viscous pastes and high-solids damp cakes. Higher mechanical shear and larger radial drag force.

### Sizing Kinematics: The 10:1 Power Ratio
- **Work Distribution**: The screw auger performs **over 90% of the mechanical displacement work** inside the cone, while the orbit arm merely guides the auger trajectory.
- **Motor Sizing Rule**: Maintain an approximate **10:1 auger-to-orbit power ratio**:
  - Screw Drive Motor: 1.5–2.2 kW (at 60–120 RPM, high breakaway torque for frozen granules).
  - Orbital Arm Motor: 0.25–0.37 kW (at 1.0–2.5 RPM).
- **Wall Clearance**: Precision tolerance of **3.0 to 5.0 mm** between auger flighting edge and the inner cone wall. Prevents thermal crust buildup while guaranteeing zero metal-to-metal contact during thermal expansion.

### Cantilevered Suspension vs. Bottom Bearing
- **Pharmaceutical Prohibition**: Bottom pintle bearings are strictly unacceptable in active freeze dryers. Submerged bottom bearings trap product fines, harbor cleaning residues (failing CIP swab tests), and risk lubricant leaching into sterile batches.
- **Cantilevered Top Suspension**: Agitator screw is suspended entirely from the orbital arm universal joint in the top dome. Eliminates 100% of submerged dynamic seals.

Twin Screw Conical Blender Internal Cutaway & Dual Orbit Head Drive

### Jacket construction options

Nauta Conical Vessel with External Spiral Half-Pipe Heating Jacket

Three jacket configurations suit the conical body:
- **Plain annular jacket**: Simple fabrication. Yields lower heat-transfer fluid velocities and lower pressure ratings.
- **Half-pipe coil jacket**: Welded semicircular pipe wrapped helically around the cone. Supports 6 to 10 bar fluid circulation from high-flow TCUs. Provides uniform velocity and heat transfer.
- **Dimple jacket**: Spot-welded sheet with hydraulic expansion. Light weight, suitable for moderate circulation pressures.

For temperature cycling between -55 °C and +80 °C, half-pipe coil jackets offer optimal structural rigidity and heat-transfer performance.

## 4. Materials of construction

- **316L Stainless Steel (UNS S31603)**: Required for all product-contact surfaces. Resists corrosive CIP chemicals and provides cryogenic toughness. Exterior structural members use 304 stainless steel.
- **ASME BPE Sanitary Finishes**: Surface finish dictates cleaning efficacy.

| BPE Designation | Maximum $R_a$ ($\mu\text{m}$) | Maximum $R_a$ ($\mu\text{in}$) | Surface Treatment |
|---|---|---|---|
| SF1 | 0.51 | 20 | Mechanical Polish |
| SF2 | 0.64 | 25 | Mechanical Polish |
| SF3 | 0.76 | 30 | Mechanical Polish |
| **SF4** | **0.38** | **15** | **Electropolished** |
| SF5 | 0.50 | 20 | Electropolished |

Specify **SF4 ($R_a \le 0.38\,\mu\text{m}$, electropolished)** for all internal product-contact walls. Electropolishing removes micro-roughness and enriches surface chromium content.
- **Chemical Passivation**: Perform acid passivation per ASTM A967 or ASTM B912 following welding and polishing.
- **Elastomer Gaskets**: Use steam-resistant EPDM or PTFE-sheathed fluoroelastomers meeting USP Class VI and FDA 21 CFR 177.2600.

### ASME Section VIII and ASME BPE are complementary

ASME Section VIII governs mechanical pressure containment, calculating shell thickness to resist buckling and rupture. ASME BPE governs hygienic integrity, defining radius geometries, weld profiles, drainability, and surface roughness. Apply both standards simultaneously to the vessel.

## 5. Pressure and vacuum vessel design

The vessel operates under full external vacuum (1.013 bar differential):
- Thin conical shells fail through **elastic buckling** before reaching material yield stress.
- Design to **ASME BPVC Section VIII, Division 1, UG-28 through UG-30**. UG-28 specifies external pressure thickness calculations with a minimum 3:1 safety margin against elastic collapse.
- In Europe, design to **EN 13445** under the **Pressure Equipment Directive (PED 2014/68/EU)**.
- Jacket shells experience simultaneous internal fluid pressure and external vacuum. Verify inner cone stability under combined loads.
- Verify cryogenic impact toughness per ASME UCS-66 for design metal temperatures down to -55 °C.

## 6. Bottom discharge valve

Zero Dead Space Pneumatic Bottom Discharge Valve Operation

Bulk Powder Discharge Mechanics: Funnel Flow Silo vs Mass Flow Conical Vessel

::youtube[https://www.youtube.com/watch?v=ZYifIAtqusM]{title="Silo Design: Mass Flow vs Funnel Flow - DEM Case Study" channel="EngineerDo" duration="1:15" context="Chapter 05 Powder Discharge Dynamics" caption="Discrete Element Method (DEM) particle simulation illustrating mass flow vs funnel flow (rat-holing) in steep conical discharge funnels, demonstrating why steep hopper angles prevent product stagnation."}

Hosokawa utilizes a sanitary **ball-segment valve** (such as the ISEM series). The spherical segment closure sits flush with the internal cone contour. This design eliminates dead legs and prevents unmixed product pockets. Sized for DN100 to DN150 clamp flanges.

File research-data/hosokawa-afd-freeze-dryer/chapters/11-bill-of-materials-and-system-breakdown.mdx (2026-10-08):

---
title: "Itemized Bill of Materials & System Component Breakdown"
chapterNumber: "11"
slug: "11-bill-of-materials-and-system-breakdown"
act: "Mechanical & Vessel Engineering"
actId: "act-2"
readTime: "2 min read"
simulators: []
---

# 11 — Itemized Bill of Materials & System Component Breakdown

> [!TIP]
> **Live Interactive BOM Explorer**:
> You can inspect, filter, and search all 73+ component specifications, ASME standards, and make/buy decisions directly in the interactive system explorer:
> 👉 **[Open Interactive BOM Table in The Bench](/hosokawa-afd-freeze-dryer/bom)**

A full line-item BOM, organized by subsystem, is provided as a companion spreadsheet: **`bom/AFD_replica_BOM.xlsx`**. This markdown file summarizes its structure and how to use it.

## Spreadsheet structure

| Sheet | Contents |
|---|---|
| `Summary` | Subsystem-level rollup: item counts, make/buy split, and a place to total your own sourced costs (cost column left blank — component pricing is region/vendor/time dependent and this package does not invent prices) |
| `BOM` | The full line-item list: Subsystem, Item, Function/Notes, Make or Buy, Suggested Source/Standard, Reference (which file in this package documents it), Qty (placeholder — depends on your batch-size design) |

## How the BOM maps to the rest of this package

Each BOM line references the file where its engineering rationale, standard, or patent citation lives — the BOM itself is deliberately kept as a structured index rather than repeating that explanation inline. Reading order:
1. Pick your target batch size (drives vessel volume — file 11's methodology, file 03's Hosokawa size table for scale intuition).
2. Work subsystem by subsystem through files 05–08 to firm up each line item's actual spec for your design.
3. Use file 10's make/buy table (already reflected in the BOM's Make/Buy column) to decide sourcing.
4. Use the BOM as your live procurement/fabrication tracking sheet as the build proceeds — add real supplier, part number, and cost columns as you source each item; the shipped template deliberately leaves these blank rather than inventing placeholder vendors or prices.

## Subsystems represented in the BOM (17 groups, matching file 04's subsystem map)

1. Lyophilisation Vessel & Chamber
2. Agitator & Drive
3. Vessel Jacket & TCU
4. Refrigeration System
5. Vacuum System
6. Material Collector / Dust Filter
7. Bottom Discharge Valve
8. CIP System
9. SIP System (optional)
10. Seals, Gaskets & Insulation
11. Instrumentation
12. Valves & Piping
13. Control System (PLC/HMI/SCADA)
14. Electrical System
15. Structural Frame
16. Utility Management Skid / Interface
17. Safety Systems

## A note on quantities and costs

This package deliberately does **not** publish per-item cost estimates or fixed quantities: real costs vary enormously by region, supplier, new-vs-surplus sourcing, and your chosen batch scale, and inventing numbers here would create false precision. The `Qty` and `Cost` columns in the spreadsheet are intentionally left for you to fill in once your own vessel size (file 11) and sourcing decisions (file 10) are fixed — use the BOM's structure and the Make/Buy/Reference columns as the durable part of this deliverable.

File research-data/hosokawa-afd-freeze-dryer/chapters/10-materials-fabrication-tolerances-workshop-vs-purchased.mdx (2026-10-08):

---
title: "Materials, Fabrication, Tolerances & Workshop vs. Purchased"
chapterNumber: "10"
slug: "10-materials-fabrication-tolerances-workshop-vs-purchased"
act: "Build It"
actId: "act-3"
readTime: "6 min read"
simulators: []
---

# 10 — Materials, Fabrication, Tolerances & Workshop vs. Purchased

::youtube[https://www.youtube.com/watch?v=Xlwxu3NfhvU]{title="Nauta Conical Vacuum Dryers | Shiv Shakkti" channel="Shiv Shakkti Process Equipment Pvt Ltd" duration="1:15" context="Chapter 10 Fabrication Workshop" caption="Shop floor manufacturing of conical vacuum dryers showing vessel cone rolling, jacket welding, mirror internal polishing, and drive skid fitment."}

::youtube[https://www.youtube.com/watch?v=8J1il5RoBGY]{title="Mixing of dry powder Cell Culture Media" channel="Hosokawa Micron B.V." duration="1:50" context="Bio-Pharmaceutical Powder Mixing" caption="Application of low-shear agitated mixing to bio-sensitive cell culture media under strict pharmaceutical GMP standards."}

Conical Screw Dryer Engineering Kinematics & Fabrication Infographic

Hosokawa Alpine Cleanroom Powder Containment & Aseptic Packaging Line

This file draws the practical make/buy line, item by item, for someone with real mechanical fabrication capability (per this package's assumption: a well-equipped workshop with manual/CNC machining and TIG welding, but not an in-house cleanroom, orbital-welding rig, or refrigeration-charging license).

## 1. General principle

Split every component into one of three buckets:
1. **Fabricate in-house** — geometry-specific, low product-safety-criticality, within normal machine-shop tolerance capability.
2. **Buy as a finished/certified component** — anything with a safety certification, a wear-seal function, a proprietary internal mechanism, or a tolerance/finish spec beyond typical shop capability.
3. **Contract out to a specialist shop** — geometry your own shop can design but not practically make to the needed tolerance/finish/certification (e.g., a code-stamped pressure vessel, an orbital-welded sanitary tube run, an electropolished vessel interior).

## 2. Item-by-item make/buy assessment

| Item | Recommended bucket | Why |
|---|---|---|
| Conical vessel shell (rolled/formed cone) | **Contract out** (specialist fabricator) for anything intended to actually hold vacuum reliably, especially if it will ever be code-stamped; **fabricate in-house** is realistic for an early, non-code, atmospheric-pressure-only mockup used to prove out agitator geometry and clearances | Rolling/forming a true cone to the tolerance needed for a consistent agitator wall clearance (file 05 §3, 0.5–15 mm target) is a real sheet-metal-forming skill; a pressure/vacuum-rated version additionally needs code-compliant welding procedures (WPS/PQR) and NDE that most home shops aren't equipped or certified to perform |
| Double jacket | **Contract out** alongside the vessel shell | Jacket welding introduces its own external-pressure case (file 05 §5) and is normally done by the same specialist shop building the inner shell |
| Top lid, clamp ring, and lid fittings' mounting bosses | **Fabricate in-house** (machining/welding) with **purchased** vacuum-rated sight glass, gauge ports, and seals | The lid geometry itself is a very tractable machining/welding project; the vacuum-rated glass and instrument fittings are safety-critical purchased components (file 09 §1) |
| Bottom discharge (ball-segment) valve | **Buy** | A precision, wear-rated sanitary valve mechanism — not a practical in-house fabrication target; source from a sanitary-valve manufacturer (Hosokawa's own ISEM brand, or equivalents from GEMU, ITT Pure-Flo, Bardiani, etc.) |
| Agitator shaft & mixing element (ribbon/paddle/screw) | **Fabricate in-house** | Geometry-specific, within normal CNC/welding capability once the vessel's exact internal profile is known — this genuinely is a good workshop-scale machining project |
| Agitator drive — magnetic coupling variant | **Buy** | A precision, matched-pair permanent-magnet assembly; commercially available as a complete unit from mag-drive coupling manufacturers serving the pressure-reactor/pharma-mixer market |
| Agitator drive — single rotary shaft seal variant | **Buy the seal**, fabricate the surrounding housing | Mechanical seals (especially any rated for vacuum + cryogenic service) are a precision, wear-rated purchased component; the housing that holds it is a fabrication project |
| Agitator drive motor + gearbox/VFD | **Buy** | Standard industrial component, no reason to fabricate |
| TCU (refrigeration + heating skid) | **Buy as an integrated package** from an industrial process-chiller/TCU manufacturer, or **assemble in-house from purchased components** (compressor, heat exchangers, pump, controller) if budget/learning goals favor building it yourself | Refrigerant circuit work legally requires appropriate certification in most jurisdictions (e.g., EPA 608 in the US) — plan for a qualified refrigeration technician regardless of which sourcing route you choose |
| Vacuum pump train | **Buy** | Precision rotating equipment; not a realistic fabrication target at any scale |
| Vacuum gauges (Pirani, capacitance manometer) | **Buy** | Precision instruments |
| Material collector / filter housing | **Fabricate in-house** (housing) + **buy** (filter screen/cartridge element) | The housing is a straightforward vessel-and-flange fabrication project; the actual filter media is a consumable, purchased component |
| Vacuum isolation & bypass valves | **Buy** | Bellows/diaphragm-sealed vacuum valves are precision, certified components |
| CIP spray nozzles/spray balls | **Buy** | Standard sanitary catalog components (Alfa Laval, Lechler, and similar spray-nozzle manufacturers) |
| Seals & gaskets (lid, ports, valve stems) | **Buy** | Elastomer/PTFE components requiring material-specific compounding and certification (esp. for SIP-rated or product-contact service) |
| Insulation & cladding | **Fabricate in-house** (cladding sheet metal) + **buy** (insulation material itself) | Straightforward sheet-metal fabrication once vessel geometry is fixed |
| Structural frame/skid | **Fabricate in-house** | A very good workshop welding/fabrication project; standard structural steel practice |
| Sensors (RTDs, thermocouples, level, torque, filter ΔP) | **Buy** | Standard purchased instrumentation |
| Pneumatic/electric valve actuators | **Buy** | Standard purchased components |
| PLC, HMI, VFDs, electrical panel components | **Buy**; panel assembly and wiring can be **in-house** if you have the relevant electrical competence | The control logic and panel-building skill is learnable and a good project; the components themselves are always purchased |
| Piping and sanitary tube/fittings | **Buy tube/fittings** (BPE-grade); **fabricate/assemble in-house** with orbital welding if you invest in that capability, or **contract out** the welding to a certified orbital-welding shop | Orbital welding equipment and certified procedure qualification is a real, learnable but non-trivial investment; contracting it out for the product-contact runs is a very reasonable choice even for an otherwise heavily DIY build |

## 3. Tolerances and surface finishes worth calling out explicitly

- **Agitator-to-wall clearance**: 0.5–15 mm, preferably 1–10 mm, per Hosokawa's own patent (file 05 §3). Achieving this consistently around a full conical revolution, accounting for thermal contraction of both the vessel and the agitator at cryogenic temperature, is the single hardest dimensional-control problem in the whole build — plan to prototype and iteratively fit this clearance (e.g., with an adjustable-mount agitator shaft/bearing arrangement) rather than assuming a one-shot machined fit will land correctly, especially across the temperature swing.
- **Surface finish, product-contact surfaces**: target **ASME BPE SF4 (Ra ≤ 0.38 µm / 15 µin), electropolished**, matching standard pharma product-contact practice (file 05 §4) — this is a specialist post-fabrication process (send the fabricated vessel/parts to an electropolishing shop) rather than an in-house finishing operation for most workshops.
- **Non-product-contact structural surfaces**: standard mechanically-polished or as-fabricated finish is acceptable; no need to electropolish the structural frame or jacket exterior.
- **Weld quality on product-contact and pressure/vacuum-boundary joints**: full-penetration, properly qualified welding procedure (WPS) with appropriate NDE (dye penetrant at minimum; radiography for critical vacuum-boundary welds on anything you intend to actually trust under full vacuum) — this is where "contract out to a specialist shop" earns its place in the table above for anything beyond an atmospheric-pressure prototype.

## 4. Suggested staged fabrication approach

Vertical Cone Screw Blender Multi-Unit Fabrication Assembly Line

Turnkey Industrial Nauta Vacuum Drying Installation Skid

1. Build a **non-vacuum, atmospheric-pressure mockup** of the vessel + agitator in-house first (even in a cheaper material like 304 stainless or even mild steel for a true first-pass geometry check), purely to validate agitator clearance, drive alignment, and general assembly — cheap to iterate, and catches the hardest dimensional problem (§3 above) before you've committed to an expensive, code-fabricated pressure/vacuum vessel.
2. Only once that geometry is proven, commission the actual vacuum-rated, BPE-finished vessel from a specialist fabricator, built to the now-validated dimensions.
3. Build up the rest of the subsystems (frame, TCU, vacuum train, material collector, controls) in parallel, since most of them don't depend on the vessel's final fabrication — see file 16 for a full staged roadmap.

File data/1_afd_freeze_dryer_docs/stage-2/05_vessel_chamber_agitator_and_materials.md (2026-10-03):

# 05 — Vessel, Chamber, Agitator & Materials

## 1. Vessel geometry

Per NL1022668C2 and NL2026893B1 (file 03), the vessel is:
- **Downward-conical** (cone point at bottom), optionally with a short cylindrical section at the top near the lid to give room for the drive, seals, and top-mounted nozzles/fittings — the patent explicitly notes this is common on "classical" conical mixers.
- A cylindrical vessel with only a conical *bottom* section is called out as an acceptable, more space-efficient variant, provided the cylindrical-to-conical proportion is chosen so mixing still works well (no numeric ratio is given in the patent — this is a design/test parameter, not a published constant).
- **Jacketed wall**: a single welded spiral-baffled or half-pipe coil jacket around the conical vessel wall, connected to a single closed-loop Thermal Control Unit (TCU). A single wide-range synthetic fluid (Syltherm XLT, -50°C to +80°C) provides both cryogenic freezing and sublimation heating without fluid swapping or nested concentric shells.
- **Open top**, closed by a **top lid** fixed with clamping screws (a quick-release clamp/tri-clamp-style closure is the generic sanitary-industry equivalent and a very reasonable workshop substitute).
- **Open bottom**, closed by a **releasable outlet** (ball-segment valve type per the patent drawings) for full discharge.

No vessel diameter, height, wall thickness, or exact cone angle is published for the AFD. For your own build, treat the vessel geometry as a design variable you solve for in file 11 based on your target batch volume, not a number to look up.

## 2. Fittings on the lid (per NL2026893B1's worked example — useful as a checklist)

- Fluid outlet (vacuum) port to the material collector, with a flanged, quick-couple connection carrying a safety switch that confirms proper coupling before the cycle can run.
- Attachment flanges for: an illumination source (sight light), a vent valve (for controlled atmosphere break), and a **sight glass** (visual inspection during the cycle — valuable for a first-time builder too).
- One or more **blow nozzles**, plumbed to a gas source, aimed into the chamber for the end-of-cycle cleanup gas pulse.
- Spray nozzle(s) for CIP (per the 2003 patent's "rotational washing nozzle").

## 3. Agitator

- **Type**: **Single cantilevered orbital screw with top planetary gearhead** (Hosokawa Nauta principle, US 6,095,677 A). While NL 1022668 C2 listed ribbon and paddle as broad claim language, both fail in real lyophilization: ribbons cause severe shear damage ($\tau > 500\text{ Pa}$) to freeze-dried powder, dam cryogenic spray droplets, and shadow CIP spray. The single orbiting screw fluidizes granules into a fountain ($U_{eff} = 65–75\text{ W/m}^2\cdot\text{K}$) with gentle shear ($\tau < 65\text{ Pa}$) and leaves the bottom apex 100% unobstructed.
- **Wall clearance**: **3–5 mm** (practical range: 1–10 mm) — tight enough to continuously renew the boundary layer without wall contact.
- **Speed**: the patent notes that because freeze-drying is inherently slow (10–100 h for a 50 L charge), **only gentle mixing action is required** — vigorous mixing isn't needed and would only add unwanted heat via mechanical work. For reference, the related Nauta mixer product line runs its screw at roughly 70 rpm with the orbiting arm at 1–2 rpm and a screw tip speed of 0.5–2 m/s (general Nauta figures, not AFD-specific — treat as a starting point, not a target).
- **Drive/seal**: two options, both explicitly disclosed:
  1. **Magnetic coupling** between an external drive motor and the internal agitator shaft — no shaft penetration through the vessel wall, essentially eliminating that vacuum leak path. This is the higher-integrity, harder-to-source-cheaply option; magnetically coupled agitator drives are a mature, commercially available product category (used widely in pressure reactors and pharma mixers) but a costed, purchased component, not something to fabricate from scratch — see file 10.
  2. **Single rotary shaft seal** where the shaft does penetrate the wall — mechanically simpler, cheaper, and easier for a first prototype, at the cost of a wear part that is also your primary vacuum leak risk.
  3. **Double mechanical seal with a pressurized sterile gas barrier** (nitrogen is standard) between the two seal faces, held at a pressure above the process side — this is not disclosed in Hosokawa's patents specifically, but it is standard, well-proven practice across the wider pharma/aseptic-reactor industry for exactly this problem (a rotating shaft penetrating an aseptic, vacuum-capable vessel). The logic is simple and worth understanding: with the barrier gas held higher than vessel pressure, any seal leakage path runs *into* the vessel (sterile nitrogen entering the product side), never product or process gas escaping outward — so a slow seal leak is a nuisance (nitrogen consumption, a pressure trend to watch) rather than a containment failure. A barrier-gas pressure switch/transmitter feeding an alarm (and, on a GMP system, a genuine SIS interlock — file 22) for low barrier pressure is standard practice alongside this seal type.
- **Bearings located outside the vessel** in both cases, specifically to keep lubricant away from cryogenic wall temperatures where it could stiffen/seize.

### Jacket construction — three real, buildable options
Hosokawa doesn't publish which jacket construction the AFD uses, but this is a well-understood, generic pressure-vessel-jacket decision worth naming explicitly, since it directly affects both your external-pressure calculation (§5 below) and your fabrication plan (file 10):
- **Plain annular jacket** (a second shell wrapped around the vessel with a simple gap): cheapest and simplest to fabricate, but gives the least uniform flow distribution and is generally limited to lower jacket-side pressure/flow.
- **Half-pipe coil jacket** (a half-round pipe section welded helically around the outside of the vessel wall): handles higher jacket-side pressure and flow (commonly 6–10 bar hydraulic, consistent with what a TCU circulating pump can readily deliver) and gives more predictable, higher-velocity flow along the helix — a common choice specifically because it suits the wide temperature swing and reasonably high flow this application needs.
- **Dimple jacket** (a pattern of welded dimples forming many small flow channels): lighter and often cheaper than a half-pipe jacket for a given heat-transfer area, popular on stainless bioprocess vessels, though typically rated for somewhat lower jacket-side pressure than a half-pipe design.

For a vessel cycling through this equipment's full temperature swing (roughly −55 °C to +80 °C or higher if used for post-SIP bake-out), a half-pipe coil jacket is the most common real-world choice in comparable stirred-vessel/reactor practice, precisely because it tolerates the higher circulation pressure a fast-responding TCU loop tends to need — but this is a design choice for you to make and cost out, not a confirmed AFD specification.

## 4. Materials of construction

Hosokawa does not publish the AFD's exact material spec, but the applicable industry standard for anything touching a pharmaceutical product is unambiguous:

- **316L stainless steel** (low-carbon 316, UNS S31603) is the default product-contact material across essentially the entire pharma/biotech process equipment industry, chosen for its corrosion resistance, weldability, and compatibility with CIP/SIP chemistries and cleaning validation. Non-product-contact structural members are commonly 304/304L stainless or, for the outer frame only, coated carbon steel.
- **ASME BPE (Bioprocessing Equipment)** is the standard governing sanitary design, dimensions/tolerances, surface finish, material joining (orbital welding), and seals for this equipment class. Its surface-finish tables (Part SF) define a series of designations:

| Designation | Max Ra (µm) | Max Ra (µin) | Preparation |
|---|---|---|---|
| SF0 | no requirement | no requirement | — |
| SF1 | 0.51 | 20 | Mechanical polish |
| SF2 | 0.64 | 25 | Mechanical polish |
| SF3 | 0.76 | 30 | Mechanical polish |
| SF4 | 0.38 | 15 | Electropolish |
| SF5 | ~0.50 | ~20 | Electropolish |
| SF6 | ~0.64 | ~25 | Electropolish |

  **SF4 (Ra ≤ 0.38 µm, electropolished)** is the most common specification for actual pharmaceutical product-contact surfaces (WFI systems, bioreactors, product-contact vessel walls). Electropolishing is a controlled electrochemical process that removes a thin surface layer to eliminate micro-asperities, leaving a smooth, passivated, low-Ra finish; it is not mandated for every surface (e.g., steam-only surfaces may use a rougher mechanical polish), but is standard practice for anything the product itself touches.
- **Passivation** (commonly per ASTM A967 or the equipment-specific ASTM B912 for electropolished surfaces) chemically restores/enhances the chromium-oxide passive layer after fabrication and welding, which is otherwise disrupted by heat-affected zones and mechanical work — required alongside surface-finish specification, not a substitute for it.
- **Elastomer seals**: typically EPDM (good steam/SIP resistance) or PTFE-faced silicone for product-contact gaskets and lid seals; material selection depends on your specific SIP temperature and any product-contact chemical compatibility requirements.

## 5. Pressure/vacuum vessel design (structural)

The vessel operates under **external pressure** (full vacuum on the inside relative to atmosphere outside) — mechanically, this is a fundamentally different, and often more demanding, design case than the same vessel holding internal pressure, because thin cylindrical/conical shells are prone to **elastic buckling** under external pressure long before the material's yield strength is reached.

- **ASME BPVC Section VIII, Division 1, UG-28 through UG-30** is the governing US code section: UG-28 gives the procedure for determining the required shell thickness under external pressure (using the vessel's L/Do and Do/t ratios against the code's material/geometry charts to find a factor used in the allowable-pressure formula); UG-29 covers when and how stiffening rings are required if a plain shell of reasonable thickness isn't enough on its own; UG-30 covers stiffening-ring attachment details. The general design margin is a **minimum 3:1 safety factor against theoretical elastic collapse**.
- In Europe, the equivalent frameworks are **EN 13445** (unfired pressure vessels) and the **Pressure Equipment Directive (PED, 2014/68/EU)**, which sets the conformity-assessment and CE-marking regime a vessel like this would need to go through for legal sale/use in the EU above its exemption thresholds.
- **Jacket walls themselves are also an external-pressure case** (the jacket's own outer wall sees the jacket fluid pressure pushing out, while the vessel's inner wall — shared with the process side — can see external pressure from the vacuum side and, depending on jacket fluid pressure and sequencing, from the jacket side too). Design guidance published by pressure-vessel engineering practitioners (e.g., Pressure Vessel Engineering Ltd.'s public "External Pressure" reference) specifically discusses jacket closures functioning (or not) as adequate vacuum-stiffening rings — this is a real, non-obvious failure mode worth deliberately checking rather than assuming the jacket automatically stiffens the inner wall.
- Given Shekhar's existing ASME Section VIII Division 1/2 pressure-vessel design background (per this package's professional-context notes), the external-pressure calculation itself (UG-28's iterative thickness/stiffening-ring procedure) is directly transferable and not new territory — the freeze-dryer-specific twist is combining it with the cryogenic operating temperature range (down to roughly −55 °C at the wall) for material toughness/MDMT (minimum design metal temperature) checks per UCS-66, and with the double-jacket geometry.

## 6. Bottom discharge valve

Both patents describe (and Hosokawa's Nauta mixer literature independently confirms) a **ball-segment valve** at the vessel's bottom outlet for full-emptying discharge — Hosokawa's own branded version of this component is sold as an "ISEM ball segment valve," explicitly marketed for conical powder mixers/dryers. Functionally, this is a quarter-turn valve with a spherical-segment closure member sized to match the cone's outlet bore with minimal dead space when closed (the patent specifically notes the closed valve sits flush with the agitator's rotational path "to eliminate any dead space"). This class of valve is a purchased sanitary process-valve component, not something to fabricate from raw stock — see file 10.

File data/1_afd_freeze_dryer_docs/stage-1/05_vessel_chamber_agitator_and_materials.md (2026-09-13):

# 05 — Vessel, Chamber, Agitator & Materials

## 1. Vessel geometry

Per NL1022668C2 and NL2026893B1 (file 03), the vessel is:
- **Downward-conical** (cone point at bottom), optionally with a short cylindrical section at the top near the lid to give room for the drive, seals, and top-mounted nozzles/fittings — the patent explicitly notes this is common on "classical" conical mixers.
- A cylindrical vessel with only a conical *bottom* section is called out as an acceptable, more space-efficient variant, provided the cylindrical-to-conical proportion is chosen so mixing still works well (no numeric ratio is given in the patent — this is a design/test parameter, not a published constant).
- **Double-jacketed wall**: two concentric compartments (per NL2026893B1's Figure 1B description) around the vessel wall, each able to carry a heat-exchange medium, so the same wall can be cooled during freezing and heated during drying without swapping fluids.
- **Open top**, closed by a **top lid** fixed with clamping screws (a quick-release clamp/tri-clamp-style closure is the generic sanitary-industry equivalent and a very reasonable workshop substitute).
- **Open bottom**, closed by a **releasable outlet** (ball-segment valve type per the patent drawings) for full discharge.

No vessel diameter, height, wall thickness, or exact cone angle is published for the AFD. For your own build, treat the vessel geometry as a design variable you solve for in file 11 based on your target batch volume, not a number to look up.

## 2. Fittings on the lid (per NL2026893B1's worked example — useful as a checklist)

- Fluid outlet (vacuum) port to the material collector, with a flanged, quick-couple connection carrying a safety switch that confirms proper coupling before the cycle can run.
- Attachment flanges for: an illumination source (sight light), a vent valve (for controlled atmosphere break), and a **sight glass** (visual inspection during the cycle — valuable for a first-time builder too).
- One or more **blow nozzles**, plumbed to a gas source, aimed into the chamber for the end-of-cycle cleanup gas pulse.
- Spray nozzle(s) for CIP (per the 2003 patent's "rotational washing nozzle").

## 3. Agitator

- **Type**: centrally-driven ribbon, centrally-driven paddle/blade, or an **orbital screw with a swing arm** — all three explicitly disclosed as viable in NL1022668C2. The orbital-screw-with-swing-arm design is the Nauta mixer's signature mechanism and the one most consistent with Hosokawa's marketing imagery.
- **Wall clearance**: **0.5–15 mm, preferably 1–10 mm** — tight enough to continuously prevent caking without metal-to-metal rubbing. This is a genuinely demanding machining/assembly tolerance for a conical geometry and is one of the harder things to get right in a workshop build (see file 10).
- **Speed**: the patent notes that because freeze-drying is inherently slow (10–100 h for a 50 L charge), **only gentle mixing action is required** — vigorous mixing isn't needed and would only add unwanted heat via mechanical work. For reference, the related Nauta mixer product line runs its screw at roughly 70 rpm with the orbiting arm at 1–2 rpm and a screw tip speed of 0.5–2 m/s (general Nauta figures, not AFD-specific — treat as a starting point, not a target).
- **Drive/seal**: two options, both explicitly disclosed:
  1. **Magnetic coupling** between an external drive motor and the internal agitator shaft — no shaft penetration through the vessel wall, essentially eliminating that vacuum leak path. This is the higher-integrity, harder-to-source-cheaply option; magnetically coupled agitator drives are a mature, commercially available product category (used widely in pressure reactors and pharma mixers) but a costed, purchased component, not something to fabricate from scratch — see file 10.
  2. **Single rotary shaft seal** where the shaft does penetrate the wall — mechanically simpler, cheaper, and easier for a first prototype, at the cost of a wear part that is also your primary vacuum leak risk.
- **Bearings located outside the vessel** in both cases, specifically to keep lubricant away from cryogenic wall temperatures where it could stiffen/seize.

## 4. Materials of construction

Hosokawa does not publish the AFD's exact material spec, but the applicable industry standard for anything touching a pharmaceutical product is unambiguous:

- **316L stainless steel** (low-carbon 316, UNS S31603) is the default product-contact material across essentially the entire pharma/biotech process equipment industry, chosen for its corrosion resistance, weldability, and compatibility with CIP/SIP chemistries and cleaning validation. Non-product-contact structural members are commonly 304/304L stainless or, for the outer frame only, coated carbon steel.
- **ASME BPE (Bioprocessing Equipment)** is the standard governing sanitary design, dimensions/tolerances, surface finish, material joining (orbital welding), and seals for this equipment class. Its surface-finish tables (Part SF) define a series of designations:

| Designation | Max Ra (µm) | Max Ra (µin) | Preparation |
|---|---|---|---|
| SF0 | no requirement | no requirement | — |
| SF1 | 0.51 | 20 | Mechanical polish |
| SF2 | 0.64 | 25 | Mechanical polish |
| SF3 | 0.76 | 30 | Mechanical polish |
| SF4 | 0.38 | 15 | Electropolish |
| SF5 | ~0.50 | ~20 | Electropolish |
| SF6 | ~0.64 | ~25 | Electropolish |
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

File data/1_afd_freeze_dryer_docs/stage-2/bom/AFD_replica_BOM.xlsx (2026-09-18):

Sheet: BOM
# | Subsystem | Item | Function / Notes | Make or Buy | Suggested Source / Standard | Package Reference | Qty (fill in) | Unit Cost (fill in) | Line Total
1 | 1. Lyophilisation Vessel & Chamber | Downward-conical vessel shell, double-jacketed | Product-contact pressure/vacuum boundary; holds product through freeze+dry | Contract out (specialist fabricator) for vacuum-rated unit; Make in-house for atmospheric mockup only | ASME BPVC Sec. VIII Div.1 UG-28 to UG-30 / ASME BPE / PED (EU) | 05, 09, 10
2 | 1. Lyophilisation Vessel & Chamber | Top lid & clamp ring | Closes vessel top; carries instrument/nozzle ports | Make | Sanitary tri-clamp style closure | 05
3 | 1. Lyophilisation Vessel & Chamber | Vacuum-rated sight glass | Visual inspection during cycle | Buy | Vacuum-glass manufacturer, rated to full vacuum + cryo temp | 05, 09
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

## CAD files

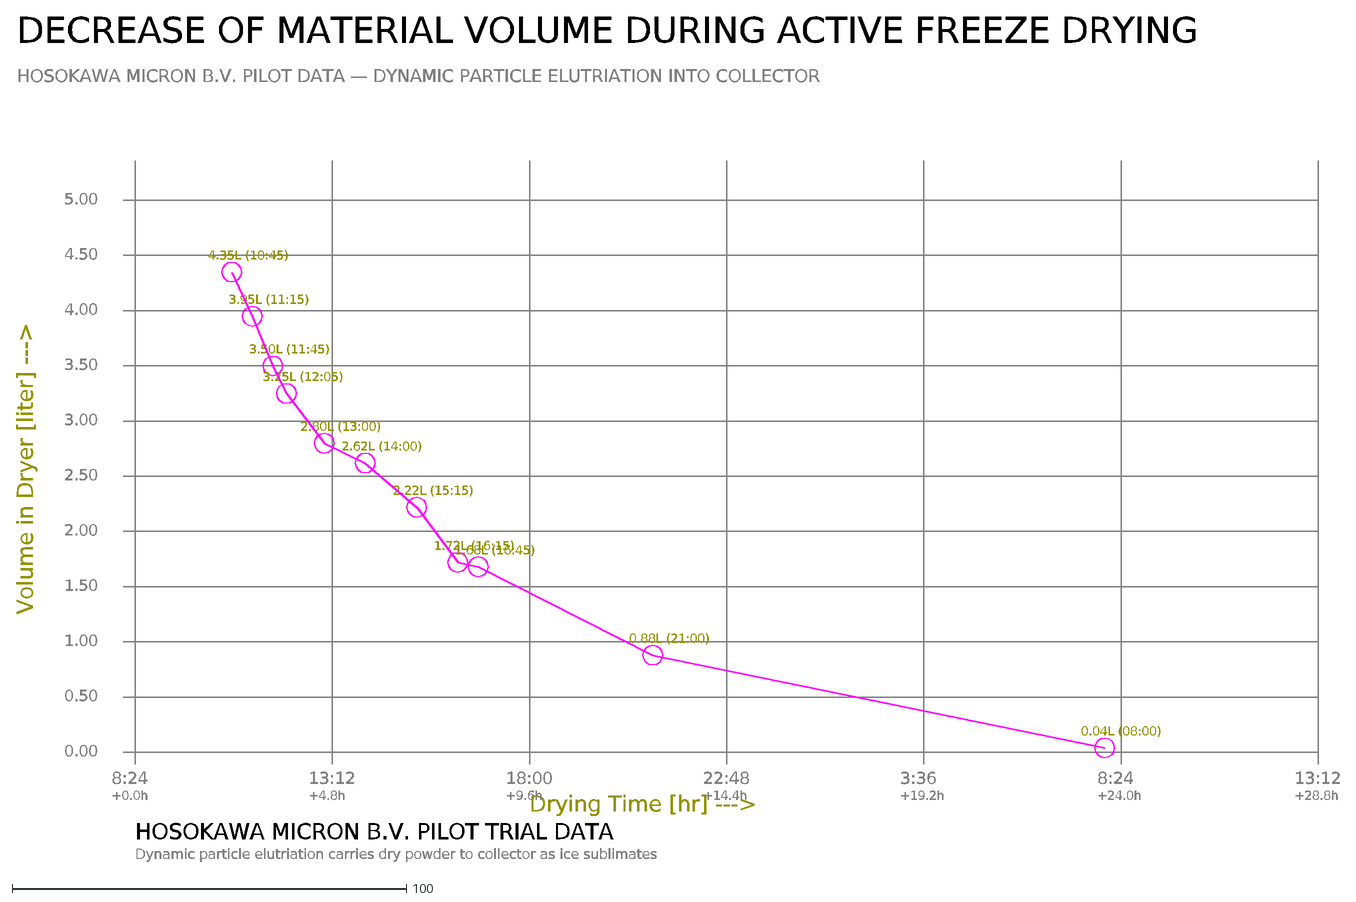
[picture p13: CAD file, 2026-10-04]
public/cad/hosokawa_afd_volume_shrinkage.dxf
DECREASE OF MATERIAL VOLUME DURING ACTIVE FREEZE DRYING
HOSOKAWA MICRON B.V. PILOT DATA — DYNAMIC PARTICLE ELUTRIATION INTO COLLECTOR
0.00
0.50
1.00
1.50
2.00
2.50
3.00
3.50
4.00
4.50
5.00
Volume in Dryer [liter] --->
Drying Time [hr] --->
8:24
+0.0h
13:12
+4.8h
18:00
+9.6h
22:48
+14.4h
3:36
+19.2h
+24.0h
+28.8h
4.35L (10:45)
3.95L (11:15)
3.50L (11:45)
3.25L (12:05)
2.80L (13:00)
2.62L (14:00)
2.22L (15:15)
1.72L (16:15)
1.68L (16:45)
0.88L (21:00)
0.04L (08:00)
HOSOKAWA MICRON B.V. PILOT TRIAL DATA
Dynamic particle elutriation carries dry powder to collector as ice sublimates

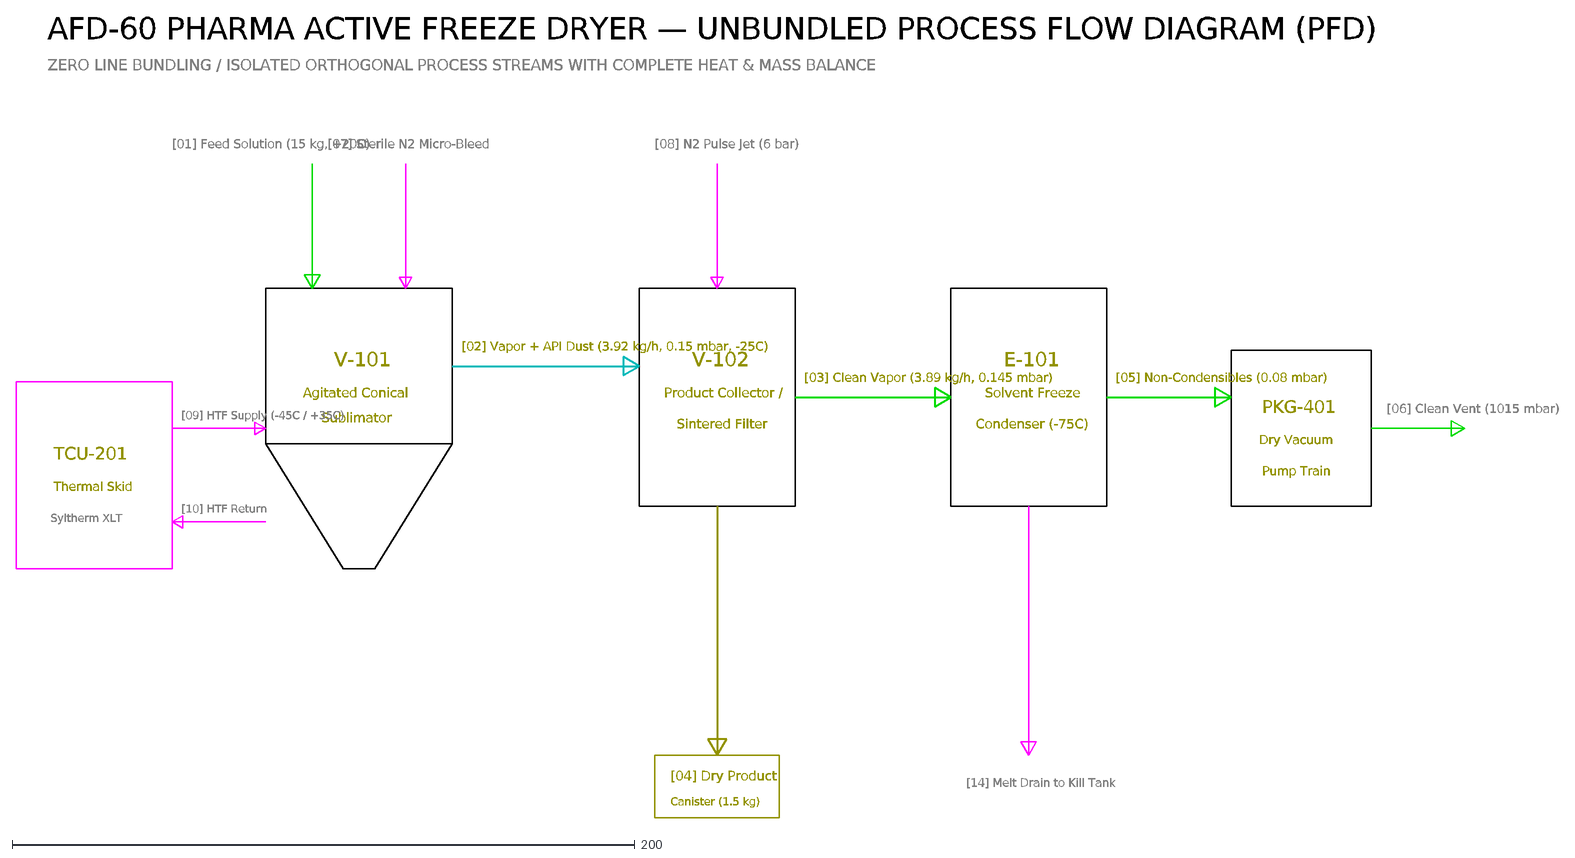
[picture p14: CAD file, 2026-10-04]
public/cad/hosokawa_afd_unbundled_pfd.dxf
AFD-60 PHARMA ACTIVE FREEZE DRYER — UNBUNDLED PROCESS FLOW DIAGRAM (PFD)
ZERO LINE BUNDLING / ISOLATED ORTHOGONAL PROCESS STREAMS WITH COMPLETE HEAT & MASS BALANCE
V-101
Agitated Conical
Sublimator
V-102
Product Collector /
Sintered Filter
E-101
Solvent Freeze
Condenser (-75C)
TCU-201
Thermal Skid
Syltherm XLT
PKG-401
Dry Vacuum
Pump Train
[01] Feed Solution (15 kg, +20C)
[09] HTF Supply (-45C / +35C)
[10] HTF Return
[07] Sterile N2 Micro-Bleed
[02] Vapor + API Dust (3.92 kg/h, 0.15 mbar, -25C)
[08] N2 Pulse Jet (6 bar)
[04] Dry Product
Canister (1.5 kg)
[03] Clean Vapor (3.89 kg/h, 0.145 mbar)
[05] Non-Condensibles (0.08 mbar)
[06] Clean Vent (1015 mbar)
[14] Melt Drain to Kill Tank

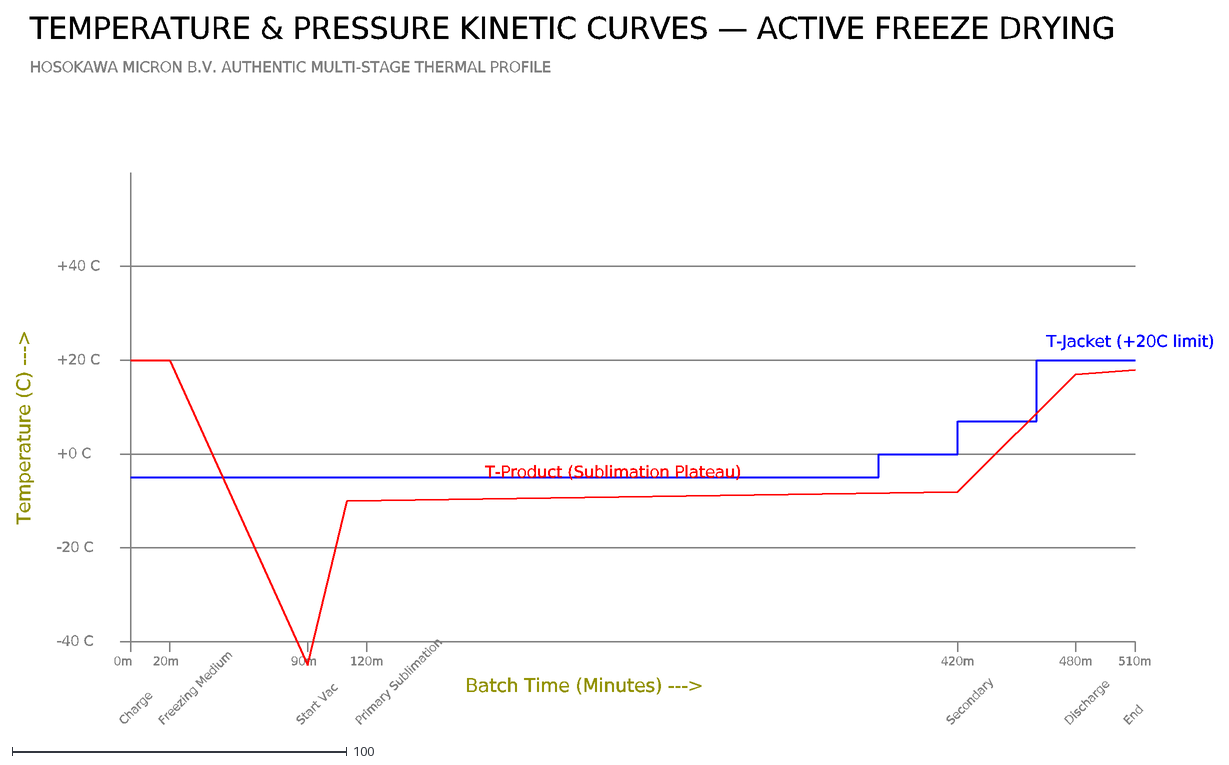
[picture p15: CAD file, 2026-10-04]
public/cad/hosokawa_afd_temp_pressure_cycle.dxf
TEMPERATURE & PRESSURE KINETIC CURVES — ACTIVE FREEZE DRYING
HOSOKAWA MICRON B.V. AUTHENTIC MULTI-STAGE THERMAL PROFILE
-40 C
-20 C
+0 C
+20 C
+40 C
Temperature (C) --->
Batch Time (Minutes) --->
0m
Charge
20m
Freezing Medium
90m
Start Vac
120m
Primary Sublimation
420m
Secondary
480m
Discharge
510m
End
T-Jacket (+20C limit)
T-Product (Sublimation Plateau)

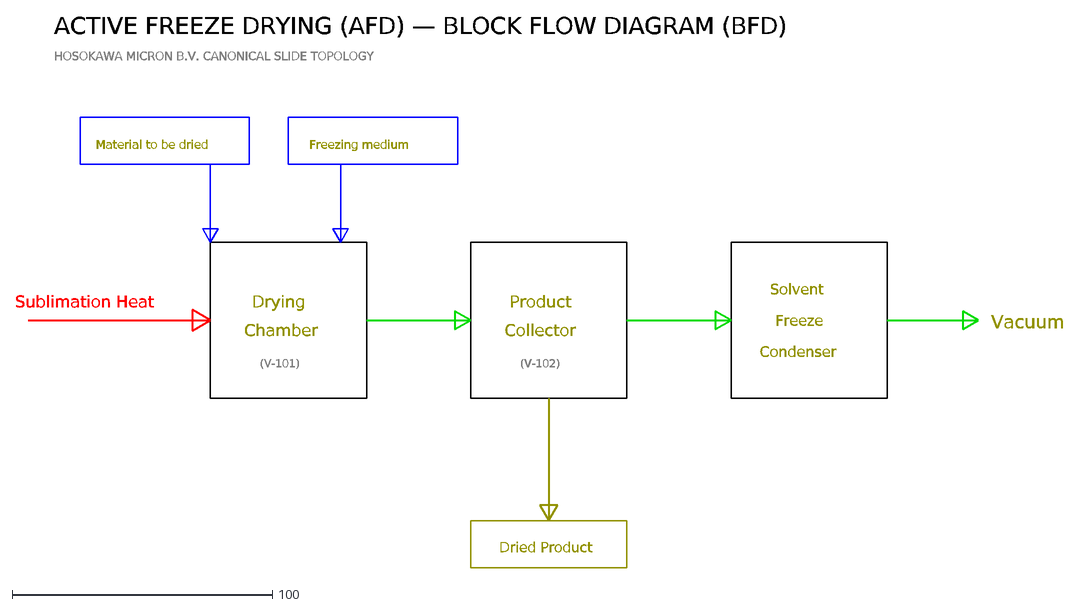
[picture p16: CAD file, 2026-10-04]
public/cad/hosokawa_afd_canonical_bfd.dxf
ACTIVE FREEZE DRYING (AFD) — BLOCK FLOW DIAGRAM (BFD)
HOSOKAWA MICRON B.V. CANONICAL SLIDE TOPOLOGY
Drying
Chamber
(V-101)
Product
Collector
(V-102)
Solvent
Freeze
Condenser
Material to be dried
Freezing medium
Sublimation Heat
Vacuum
Dried Product

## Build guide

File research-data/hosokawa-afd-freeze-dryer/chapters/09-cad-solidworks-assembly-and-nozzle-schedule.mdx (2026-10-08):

---
title: "CAD SolidWorks Assembly Hierarchy & Nozzle Schedule"
chapterNumber: "09"
slug: "09-cad-solidworks-assembly-and-nozzle-schedule"
act: "Mechanical & Vessel Engineering"
actId: "act-2"
readTime: "12 min read"
simulators: []
---

# 09 — CAD SolidWorks Assembly Hierarchy & Nozzle Schedule

See `pid_controls_data/cad_equipment_nozzle_schedule.json` for the full structured schedule this file explains. This is written specifically for the moment you sit down in SolidWorks: it's the list of *what needs a nozzle, what standard that nozzle follows, and what rating the surrounding shell needs to be modeled to* — the information a P&ID alone doesn't give you, because a P&ID deliberately shows process connectivity, not physical geometry.

## 1. Why a separate schedule from the P&ID

The P&ID (file 19) tells you *that* the vessel has a vapor outlet to the material collector. It doesn't tell you *what size that nozzle is, what flange or clamp standard it uses, or what gasket material to specify*. That's exactly the gap this file and its JSON close — it's the traditional handoff document between a process engineer and a mechanical/CAD engineer on any real project, and there's no reason to skip it just because it's currently a one-person project.

## 2. Reading the equipment schedule

For each major tag, the schedule gives: a capacity/volume basis, **design pressure on both the process side and the jacket side separately** (these are genuinely different numbers — the process side lives mostly under vacuum with a modest positive-pressure allowance, while a half-pipe-coil jacket needs a materially higher rating to handle real circulation pressure, file 05's addendum), a design temperature range with margin above your actual operating range (this margin matters for material toughness/MDMT checks per file 05 §5, not just as a round-number buffer), and materials of construction split between product-contact and non-product-contact surfaces (file 05 §4, file 10). Package equipment (`PKG-301`, `PKG-401`, `TCU-201`, etc.) is deliberately left light on internal detail — you don't design a vendor's vacuum pump train, you model its purchased envelope and nozzle-connection drawing once you've selected a vendor.

## 3. Reading the nozzle schedule

Thirteen nozzles are listed against the vessel (`V-101`) — this is a realistic, complete count for this kind of machine, not a partial list. A few worth flagging:

- **N2 (vapor outlet) deliberately doesn't get a fixed size** — it's sized by a real vacuum-conductance calculation (file 08 §6's note that vacuum lines want to be short and large-diameter), not by convention. Undersizing this one nozzle is one of the easier ways to quietly bottleneck your whole vacuum system's real-world pumping speed regardless of how well the pump itself is specified.
- **N5 (agitator shaft penetration) has no standard DN size at all** — because it isn't a process nozzle in the usual sense; its geometry is dictated entirely by whichever magnetic-coupling or mechanical-seal assembly you purchase (file 05 §3 and its addendum). Get this vendor's mounting-flange drawing *before* finalizing the lid geometry in CAD, not after — it's one of the few components on this machine where the purchased part's geometry should drive your design rather than the other way around.
- **N12 (bottom discharge) is deliberately shown with two possible connection philosophies**: a straightforward sanitary Tri-Clamp for a first prototype, or an aseptic split-valve docking connection (the kind of device that lets a canister or vial-filler connect and disconnect without ever exposing the powder to room air) if you're building toward the fully aseptic operation Hosokawa's own literature describes for the real AFD (file 18, source 21). Decide which philosophy you're building toward *before* modeling this nozzle in detail, since the two approaches have quite different envelope and clearance requirements underneath the vessel.
- **Face-to-face dimensions are deliberately not invented for the Tri-Clamp/ISO-K fittings.** Sanitary clamp fittings don't really have a single "face-to-face" dimension the way a flanged pipe spool does — their geometry is fully defined by the ISO 2852/DIN 32676 (Tri-Clamp) or ISO 2861 series (ISO-K/ISO-KF vacuum flange) standards for whatever nominal size you choose. Pull the real numbers from those standards (or your fitting vendor's own catalog drawing, which will cite the same standard) when you model each nozzle — that's a five-minute catalog lookup once you've chosen sizes, and it will be more accurate than any number this package could give you generically.

## 4. Reading the valve schedule

The one column worth thinking about carefully, valve by valve, is **fail position** — what a valve does if it loses air supply or electrical signal, which is a genuine safety design decision, not a default setting:
- Most valves here fail **closed (FC)** — losing power/air should not, by itself, create a new hazardous condition (e.g., `FCV-201` failing closed simply stops jacket flow, which is safe).
- `PV-102` (the vessel-to-collector vacuum path) is flagged as needing real thought: failing open toward atmosphere would break vacuum uncontrolled mid-cycle, which is its own kind of process upset — so fail-closed or fail-in-last-position is generally preferable, but confirm this against your own safe-state analysis (file 09, file 22) rather than copying this schedule blindly.
- `XV-104` (the vent/vacuum-break valve) is the one genuinely debatable case: some designs deliberately choose **fail-open** here specifically *so that* a total power/air loss automatically breaks vacuum and returns the vessel toward a safe, atmospheric, accessible state — this is a legitimate alternative safety philosophy to "everything fails closed," and which one is right depends on which failure mode you've judged more dangerous for your specific installation (an uncontrolled vacuum break vs. a vessel stuck under vacuum with no power). This is exactly the kind of decision a real HAZOP/LOPA exercise (file 09 §6, file 22 §2) is meant to resolve deliberately rather than by default.

## 5. What to do with this in SolidWorks, practically

A reasonable modeling sequence: block in the vessel shell and jacket geometry first (file 05, sized via file 11) with placeholder nozzle bosses at the thirteen locations above; source real vendor drawings for the purchased items that dictate their own interface geometry (the agitator seal/coupling, the discharge valve, the sight glass, the vacuum pump train's inlet flange) and drop those in as the true geometric constraints they are; then finalize nozzle sizes, orientations, and standard-compliant dimensions once those vendor interfaces are locked, rather than the other way around. This avoids the common and frustrating rework of having designed a beautiful vessel around a nozzle size or orientation that turns out not to match the seal or valve you actually end up buying.

---

## Design Basis

| Parameter | Specification / Basis |
|---|---|
| **Batch Capacity** | 10-50 kg wet product (illustrative range - re-size per file 11 for your own target) |
| **Base Vacuum** | < 0.01 mbar |
| **Operating Drying Vacuum** | 0.04-0.15 mbar (within Hosokawa's own patent-disclosed 5-0.01 mbar range, file 03 SS2a) |
| **Condenser Temperature** | -60 degC continuous ice loading, -75 degC ultimate base (illustrative - size per file 06 refrigeration method) |
| **Jacket Temperature Range** | -60 degC (freezing) to +80 degC (secondary drying); allow design margin to ~+150 degC if SIP-equipped (file 07 SS2, file 23 SS2) |
| **Heat Transfer Fluid Example** | Dow Syltherm XLT or equivalent wide-range silicone HTF (usable range approx -100 to +260 degC) - a real, named, verifiable example; not a confirmed Hosokawa specification |

## Major Equipment Schedule

| Tag | Description | Process Rating | Jacket Rating | Design Temp | Product Contact MOC | Notes |
| --- | --- | --- | --- | --- | --- | --- |
| `V-101` | Lyophilisation Vessel (double-jacketed, downward-conical) | Full Vacuum (FV) to +1.5 barg | FV to +6 to +10 barg (half-pipe coil jacket, file 05 addendum) | -60 degC to +150 degC (includes SIP margin) | 316L stainless, Ra <= 0.4 um (SF4 electropolished, file 05 SS4 / file 10) | External-pressure design per ASME BPVC VIII-1 UG-28/UG-29 or PED/EN13445 (file 05 SS5) - contract to specialist fabricator, file 10 |
| `M-101` | Agitator drive assembly (motor + VFD + seal/mag-drive housing) | N/A (seal/coupling rated to vessel design pressure) |  | ambient (bearings/motor kept outside cold zone, file 05 SS3) | 316L wetted shaft/agitator element | Purchased component (magnetic coupling, mechanical seal, or double-seal + N2 barrier per file 05 addendum) - not fabricated in-house, file 10 |
| `V-102` | Material Collector / Dust Filter housing | FV to +1.5 barg (blowback pulse) |  | -60 degC to +100 degC | 316L, Ra <= 0.4 um | Housing fabricated in-house or by specialist shop; filter media purchased/consumable, file 10 |
| `E-101` | Condenser (refrigerated coil, catches bulk water vapor) | FV to +0.5 barg |  | -85 degC to +30 degC | 316L | Purchased or specialist-fabricated heat exchanger |
| `PKG-401` | Vacuum Pump Train (Roots/dry-screw combination) | per vendor rating |  | per vendor rating | vendor-specified (typically 316L wetted parts) | Purchased vendor package - CAD model uses vendor envelope/nozzle drawing, file 10 |
| `TCU-201` | Temperature Control Unit skid | N/A (HTF loop, low pressure) |  | -100 degC to +260 degC (HTF-limited, e.g. Syltherm XLT range) | N/A (non-product-contact utility loop) | Purchased/assembled package, file 06 SS1, file 10 |
| `PKG-301` | Cascade Refrigeration Skid | N/A (refrigerant circuit, per refrigerant code) |  | per refrigerant selection | N/A | Purchased vendor package; refrigerant work requires certified technician, file 09 SS2 |
| `PKG-501` | CIP Skid | per CIP supply pressure (typically < 5 barg) |  | ambient to +85 degC (heated wash) | 316L wetted skid components | Purchased vendor package, file 07 SS1 |
| `PKG-502` | Clean Steam Package (SIP, optional) | per clean steam supply (typically 2-4 barg saturated) |  | up to ~145 degC saturated steam | 316L wetted skid components | Optional; purchased vendor package, file 07 SS2 |

## Vessel Nozzle Schedule (V-101)

| Nozzle | Function | Size / Range | Connection Standard | Gasket MOC | Face-to-Face / Notes |
| --- | --- | --- | --- | --- | --- |
| **N1** | Product/CIP charge inlet | DN40-DN65 | Sanitary Tri-Clamp per ISO 2852 / DIN 32676 Series A | USP Class VI EPDM or PTFE-encapsulated silicone | Tri-Clamp is a ferrule/clamp joint, not a flanged spool - take ferrule OD and clamp geometry from ISO 2852/DIN 32676 tables for the chosen DN, not a fixed face-to-face figure |
| **N2** | Vapor outlet to material collector (PV-102 line) | DN80-DN150 (size per vacuum conductance calc, file 08 SS6 - larger and shorter is better for vacuum lines) | ISO-K vacuum flange (larger vacuum lines) or Tri-Clamp for smaller pilot units | Vacuum-rated elastomer O-ring (ISO-K) or PTFE/EPDM (Tri-Clamp) | Pull exact ISO-K flange OD/bolt circle from ISO 2861 series dimension tables for the chosen DN - not invented here |
| **N3** | Vent / vacuum-break inlet (XV-104, via F-101 sterile filter) | DN15-DN25 | Tri-Clamp per ISO 2852 | USP Class VI EPDM |  |
| **N4** | Sight glass (LG-101) | DN40-DN65 (per vendor sight-glass assembly) | Vendor-specific vacuum/cryo-rated sight glass flange | Per vendor - PTFE or EPDM typical |  |
| **N5** | Agitator shaft penetration (drive/seal housing mount) | Sized to selected seal/mag-drive vendor's mounting flange - not a standard sanitary DN | Vendor-specific per magnetic coupling or double mechanical seal selection, file 05 addendum | Per vendor |  |
| **N6** | Blow nozzle gas inlet (end-of-cycle cleanup) | DN10-DN15 | Tri-Clamp or NPT/BSP threaded instrument connection | USP Class VI EPDM |  |
| **N7** | Jacket HTF supply | DN25-DN40 (size per file 11 flow/duty calc) | Tri-Clamp (low pressure) or welded/threaded per half-pipe jacket design pressure, file 05 addendum | EPDM (wide temperature range) |  |
| **N8** | Jacket HTF return | DN25-DN40 | Same as N7 | EPDM |  |
| **N9** | SIP clean steam inlet (optional) | DN15-DN25 | Tri-Clamp, steam-rated gasket | EPDM (steam-grade, not standard EPDM compound) |  |
| **N10** | Pressure instrument ports (PIT-101A, PIT-101B) | DN25 x2 | Tri-Clamp instrument tee or dedicated diaphragm-seal boss | USP Class VI EPDM |  |
| **N11** | Product temperature probe port | DN15-DN25 | Tri-Clamp thermowell fitting | USP Class VI EPDM |  |
| **N12** | Bottom discharge (to XV-105) | DN100-DN200 (large - sized for powder flow, not liquid flow assumptions) | Sanitary Tri-Clamp for a first build; a split-valve aseptic transfer connection (e.g. an Alpha-Beta-style split butterfly valve) if docking directly to a canister/vial-filler as Hosokawa's own literature describes, file 18 source 21 | USP Class VI EPDM |  |
| **N13** | Vacuum relief valve (VRV-101) mount | DN25-DN40 (per relief device vendor sizing - a real relief calc, not a nominal guess) | Vendor-specific relief valve connection | Per vendor |  |

## Valve Schedule & Fail Positions

| Valve Tag | Valve Type | Actuation | Fail Position | Connection |
| --- | --- | --- | --- | --- |
| `FCV-201` | Control valve, diaphragm or globe body | Pneumatic modulating, 4-20mA positioner | **Fail-Closed (FC) recommended - loses jacket flow safely on air/signal loss** | Tri-Clamp or flanged per line size |
| `PV-102` | Control valve, 3-position (open/closed/throttle) | Pneumatic modulating with positioner, or electric motorized actuator | **Fail-Open (FO) to atmosphere side is NOT appropriate here (would break vacuum uncontrolled) - Fail-Closed or Fail-Last-Position recommended; confirm against your specific safe-state analysis** | Per N2 vacuum line connection standard |
| `XV-103` | On/off valve (bypass) | Pneumatic spring-return | **Fail-Closed (FC)** | Per N2 line |
| `XV-104` | On/off valve (vent/vacuum-break) | Pneumatic spring-return | **Fail-Closed (FC) as default; some designs prefer Fail-Open here as a passive vacuum-break on air/power loss - a deliberate safety design decision, not a default, see file 09** | Per N3 line |
| `XV-105` | Ball-segment discharge valve | Pneumatic, spring-return or double-acting per vendor | **Fail-Closed (FC)** | Per N12 line - sanitary or split-valve aseptic docking |
| `XV-106` | On/off valve (filter blowback gas) | Pneumatic solenoid, fast-acting | **Fail-Closed (FC)** | Small-bore Tri-Clamp or push-fit instrument fitting |
| `PV-502` | Control valve (SIP steam) | Pneumatic modulating with positioner | **Fail-Closed (FC)** | Per N9 line, steam-rated trim |
| `VRV-101` | Vacuum relief valve (passive, spring or weight-loaded) | Self-acting (no external power/signal) | **N/A - inherently fail-safe by design** | Per N13 |
| `PSV-501` | Steam relief valve (passive, spring-loaded) | Self-acting (no external power/signal) | **N/A - inherently fail-safe by design** | Per SIP steam supply line |

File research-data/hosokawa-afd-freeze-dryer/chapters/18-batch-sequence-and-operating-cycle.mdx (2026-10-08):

---
title: "Automated Batch Sequence, SCADA Phases & Recipe Cycle"
chapterNumber: "18"
slug: "18-batch-sequence-and-operating-cycle"
act: "Electrical, Controls & Safety Automation"
actId: "act-4"
readTime: "6 min read"
simulators: []
---

# 18 — Automated Batch Sequence, SCADA Phases & Recipe Cycle

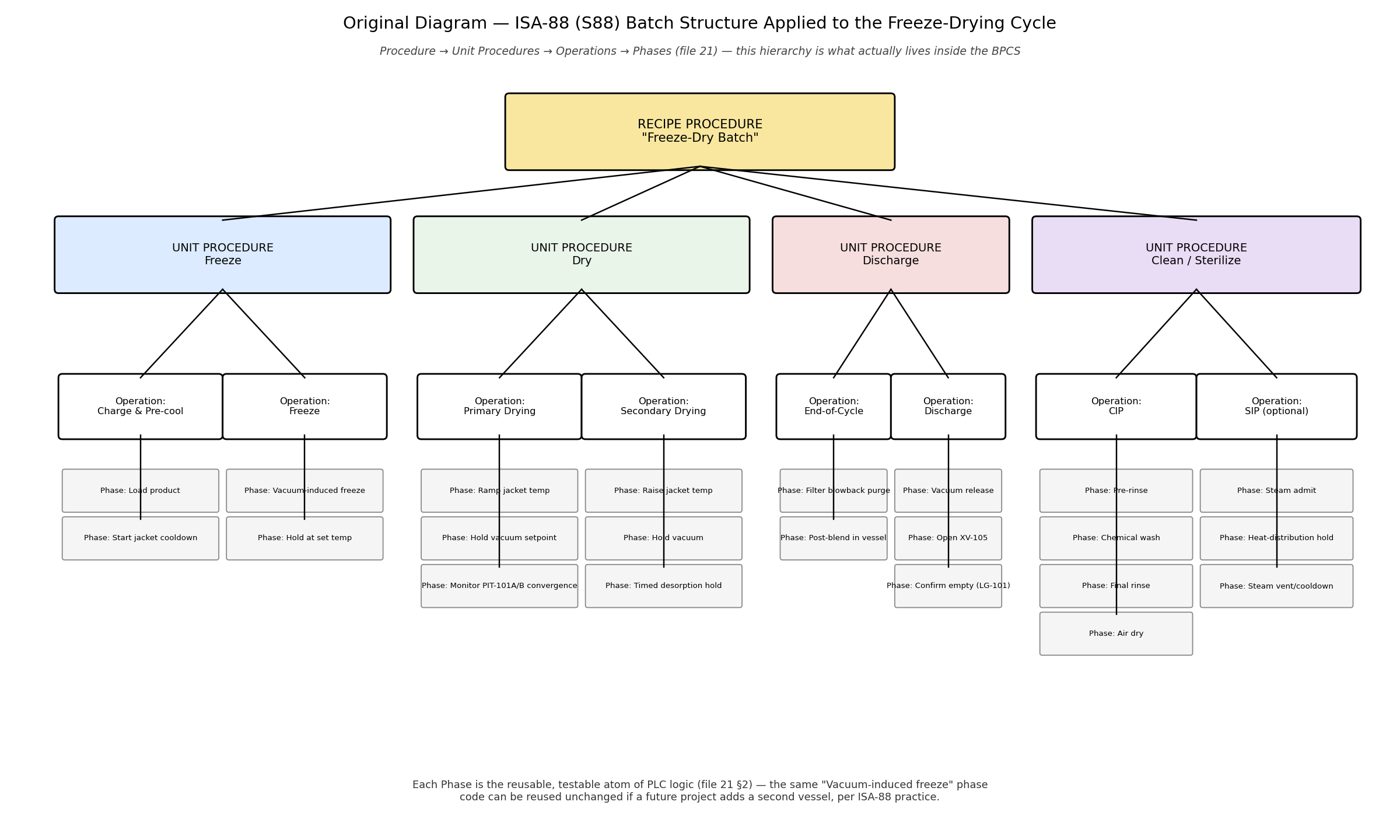
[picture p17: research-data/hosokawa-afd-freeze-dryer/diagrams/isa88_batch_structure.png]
ISA-88 Batch Structure & Phase State Machine


## 1. Why structure the recipe at all, instead of just writing PLC code

The tempting approach is to write one long PLC program that does "step 1, then step 2, then step 3...". It works, right up until you need to change one step, add a second vessel, or explain to someone else what the machine actually does — at which point a flat, unstructured program becomes very hard to safely modify. **ISA-88 (also published as IEC 61512)**, the international batch-control standard, solves this by breaking any batch process into four nested levels that stay the same regardless of what you're actually manufacturing:

<Isa88HierarchyChart />

**Phases are the important idea.** A phase is small enough to test in isolation, and — this is the payoff — genuinely reusable. "Vacuum-induced freeze" as a phase doesn't care whether it's phase 3 of today's recipe or phase 7 of a future recipe on a second vessel; it's the same tested block of logic either time. This is exactly the property that makes a control system maintainable as it grows, and it's why this structure, not a flat program, is what actually lives inside the BPCS (file 20).

## 2. This machine's cycle, mapped onto that structure

| Unit Procedure | Operations | Phases |
|---|---|---|
| **Freeze** | Charge & Pre-cool | Load product · Start jacket cooldown |
| | Freeze | Vacuum-induced freeze · Hold at set temperature |
| **Dry** | Primary Drying | Ramp jacket temperature · Hold vacuum setpoint · Monitor `PIT-101A`/`PIT-101B` convergence |
| | Secondary Drying | Raise jacket temperature · Hold vacuum · Timed desorption hold |
| **Discharge** | End-of-Cycle | Filter blowback purge · Post-blend in vessel |
| | Discharge | Vacuum release · Open `XV-105` · Confirm empty (`LG-101`) |
| **Clean/Sterilize** | CIP | Pre-rinse · Chemical wash · Final rinse · Air dry |
| | SIP (optional) | Steam admit · Heat-distribution hold · Steam vent/cooldown |

This is the same nine-step cycle already walked through narratively in file 04 §2 — ISA-88 is simply the formal, industry-standard way of writing that same cycle down so a PLC program (and the people maintaining it) can treat each piece as an independent, testable building block instead of one monolithic script.

## 3. How a phase actually behaves (the part that removes the "PLC code = magic" feeling)

Every phase, regardless of what it does physically, follows the same simple state pattern — this is the other half of what ISA-88 standardizes, and it's worth internalizing because it's the same pattern in every phase you'll ever write for this machine:

<BatchStateTransitionChart />

Take "Hold vacuum setpoint" as a concrete example: it goes **RUNNING** when the primary-drying operation starts it; it stays RUNNING as long as `PIC-101` is successfully holding pressure near setpoint; it goes to **COMPLETE** when the recipe's time or convergence condition (§4 below) is satisfied; and if `PDT-102` trips high or the SIS fires (file 22), it goes to **ABORTING** and then **ABORTED**, handing control to whatever safe-state logic that fault requires. Every phase in the table above can be described this same way — once you've written the state pattern for one phase, you already understand the shape of all of them.

## 4. Quantitative Automated Transition Logic: Ending Primary Drying

Most phase transitions in a batch recipe rely on fixed timers or operator manual prompts. However, guessing a fixed primary drying duration carries severe risks:
- **Ending too early**: Unsublimated ice remains in the core. When the jacket heats up for Secondary Drying, the ice melts into liquid water (**eutectic meltback**), causing irreversible cake collapse, degradation of active APIs, and batch rejection.
- **Running too long**: Wastes tens of machine hours and energy, and exposes sensitive biologics to unnecessary thermal/vacuum stress.

The Hosokawa AFD BPCS automates this transition through two complementary, non-invasive Process Analytical Technology (PAT) gates:

### Gate 1: Comparative Pressure Divergence (`PIT-101A` vs `PIT-101B`)
As derived in Chapter 06 §3b, the Pirani gauge (`PIT-101B`) measures gas thermal conductivity (which is $\sim 1.6\times$ higher for pure water vapor than dry nitrogen), while the Capacitance Manometer (`PIT-101A`) measures true physical force via diaphragm deflection.
- **Active Sublimation State**: Water vapor dominates the vessel head. The ratio $P_{Pirani} / P_{CM}$ remains between **$1.55$ and $1.70$**.
- **Depletion State**: As frozen ice sublimates to completion, water vapor evolution ceases. The chamber atmosphere shifts to background dry nitrogen ingress. The Pirani reading drops rapidly toward the true absolute pressure.
- **Automated SCADA Trigger**:
  $$\text{Condition}: \quad \Delta P = P_{Pirani} - P_{CM} < 0.010\text{ mbar} \quad \text{AND} \quad \frac{P_{Pirani}}{P_{CM}} \le 1.05 \quad \text{for } \ge 15\text{ consecutive minutes}$$
  When this condition is met, primary drying is mathematically verified as complete.

### Gate 2: Automated Pressure Rise Test (PRT) / Manometric Temperature Measurement (MTM)
To provide secondary verification per cGMP protocols, the PLC performs an automated Pressure Rise Test:
1. The vapor isolation valve (`XV-104`) between the vessel and the condenser closes briefly for $\Delta t = 15\text{ seconds}$.
2. If ice is still sublimating, the pressure rises sharply:
   $$\left.\frac{dP}{dt}\right|_{t=0} = \frac{\dot{m}_{sub} \cdot R \cdot T}{M_{H2O} \cdot V_{vessel}}$$
3. If $dP/dt < 0.002\text{ mbar/s}$ (attributable solely to the baseline leak rate $Q_{leak} \le 0.010\text{ mbar}\cdot\text{L/s}$), the PLC confirms that sublimation has zero remaining mass flux.
4. The valve reopens, and the recipe automatically advances to the **Secondary Drying (Desorption)** phase, ramping the jacket temperature from $0^\circ\text{C}$ to $+30^\circ\text{C}$ with zero risk of meltback.

## 5. The full batch as one state diagram

Section 3 showed the generic state pattern *every individual phase* follows. This section shows the top-level state machine for **the whole batch procedure** — the sequence an operator or a supervisory recipe manager actually watches move forward. This is a good artifact to keep in this exact form (Mermaid renders natively in GitHub, most modern documentation tools, and — per your Research Data site's own publishing rules — directly in a `.md` file or inside a `<pre class="mermaid">` block on a published page) rather than only as a picture:

<FullBatchProcedureChart />

A few things worth noticing in this diagram: **`VACUUM_BREAK` uses sterile gas (nitrogen or filtered sterile air), never plant compressed air directly** — this is what keeps the whole discharge aseptic, consistent with Hosokawa's own description of the AFD as a fully sterile, closed process (file 03). **`ABORT` is reachable from every drying-related state, but only the SIS decides when that transition fires** — the BPCS recipe logic itself never overrides a genuine safety trip; it only reacts to one after the fact (file 20 §3). And **`LEAK_TEST` sits before `PRODUCT_CHARGE`**, not after — verifying vacuum integrity on an empty, cleaned vessel before committing real product to a batch is the same discipline file 15's commissioning plan asks for, just now built into the routine production cycle itself rather than only being a one-time commissioning step.

## 6. Recipe vs. equipment — the other half of ISA-88

ISA-88 also separates **what you want to do** (the recipe: target temperatures, hold times, vacuum setpoints — the "formula") from **how the equipment physically does it** (the phase logic wired to `TIC-201`, `PIC-101`, etc.). In practice this means: if you later need to run a *different* product with different hold times and temperatures on the *same* machine, you write a new recipe (a new set of parameters) rather than a new PLC program. This is the standard's biggest practical payoff for anyone planning to iterate on process development (file 16's roadmap) rather than build one fixed, never-changing cycle.

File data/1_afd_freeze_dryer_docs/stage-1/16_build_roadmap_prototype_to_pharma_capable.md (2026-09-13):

# 16 — Build Roadmap: Prototype → Pharma-Capable System

A realistic, staged path — each stage should be substantially complete and tested (file 15) before committing significant resources to the next.

## Stage 0 — Study & design (this package's files 01–13)
**Goal:** understand the physics, the AFD-specific mechanical architecture, and produce your own design calculations and drawing package before spending money on fabrication.
- Work through files 01–03 until the AFD-vs-generic distinction (file 03) is second nature.
- Pick a target batch size and run file 11's sizing methodology for *your* chosen scale.
- Produce drawings 1–3 from file 13 (GA, vessel, agitator) at minimum before proceeding.
- **Exit criterion:** you can explain, from memory, why the vessel is conical, why it's agitated, why the drying happens in that order, and roughly what heat/refrigeration/vacuum duty your chosen batch size needs — plus a first-pass vessel and agitator drawing.

## Stage 1 — Non-vacuum mechanical mockup
**Goal:** de-risk the hardest dimensional problem (agitator-to-wall clearance, file 05 §3 / file 10 §3) cheaply, before committing to an expensive vacuum-rated vessel.
- Fabricate a cheap-material (mild steel or 304 stainless), atmospheric-pressure-only vessel + agitator + drive, exactly to your Stage-0 geometry.
- Confirm the agitator clears the wall consistently around a full rotation, at every height, including after simulating thermal contraction if practical.
- Confirm drive alignment, seal/coupling fit, and basic assembly/disassembly practicality.
- **Exit criterion:** the mockup assembles, the agitator spins freely through its full range with the intended clearance, and you've identified and fixed any interference or alignment problems.

## Stage 2 — Bench-scale cold/vacuum prototype (small batch, no CIP/SIP, atmospheric-adjacent instrumentation)
**Goal:** a genuinely working small-scale freeze dryer — the point where you first sublime real ice under real vacuum in your own machine.
- Commission (or, if within your fabrication capability and risk tolerance, build) a small, properly designed vacuum-rated vessel per Stage-0's now-validated geometry (file 10's make/buy guidance strongly favors *contracting out* this specific component, even at small scale).
- Add a minimal TCU (even a simple mechanical chiller + heater arrangement is fine at this stage — a full cascade refrigeration system, file 06 §2, can wait until you need temperatures colder than a single-stage system provides), a basic vacuum pump train, and the two pressure gauge types (file 06 §3b).
- Add basic instrumentation and either manual or simple relay/PLC control — full GAMP5/Part-11-oriented control architecture (file 08 §3) is not a Stage-2 priority.
- Run file 15's Stages 1–6 commissioning tests.
- Run your first real batches (plain water ice is a good, safe, cheap first test product) and validate your file-11 calculations against reality.
- **Exit criterion:** you can reliably freeze, evacuate, sublime, and discharge a small batch, with your instrumentation confirming the process actually followed the physics in file 02.

## Stage 3 — Pilot-scale system with full subsystem set
**Goal:** a machine with every subsystem from file 04's map present, at a scale meaningful for real process development (roughly Hosokawa's own "R&D scale," ≤~20 L, per file 03 §1).
- Add the material collector/valve-bypass arrangement (file 06 §5, per NL2026893B1) if your Stage-2 prototype used a simpler straight-through vacuum path.
- Add a proper cascade refrigeration system if your target product needs colder than a single-stage system reaches (file 06 §2).
- Add CIP capability (file 07 §1) — this is also where cleaning-validation thinking (even informally) starts paying off.
- Move to a real PLC/HMI control architecture (file 08 §3), even if not yet pursuing formal GAMP5/Part 11 compliance.
- Run file 15's full commissioning plan, Stages 1–8.
- **Exit criterion:** a machine you could comfortably use for real process-development work — testing different products, freezing rates, and drying schedules — with good data logging to support that development.

## Stage 4 — GMP-capable system (only if the goal is genuinely regulated manufacturing)
**Goal:** the point where file 14's qualification framework actually applies.
- This stage is organizationally, not just technically, different: it requires operating inside (or building) a licensed quality system, with the URS→DQ→IQ→OQ→PQ lifecycle (file 14 §2) run by or with qualified validation professionals, SIP capability if aseptic processing is required (file 07 §2), full ATEX/DHA-driven explosion protection sized by a process-safety engineer (file 09 §4), and 21 CFR Part 11-compliant electronic records (file 08 §3).
- **Realistic framing:** most individuals or small teams reach Stage 3 as an excellent, legitimate engineering achievement and personal/professional credential. Stage 4 is a different kind of undertaking — organizational, regulatory, and capital-intensive — not simply "Stage 3 built to tighter tolerances." Treat reaching Stage 3 as the natural endpoint of a self-directed build, and Stage 4 as something pursued through employment, partnership, or a formally licensed manufacturing venture rather than as a solo workshop project.

## Suggested overall sequencing logic

Notice that Stages 1–3 deliberately front-load the **hardest and most failure-prone mechanical problem** (agitator clearance) into the cheapest possible stage (Stage 1, non-vacuum mockup), and defer the **most expensive and safety-critical subsystems** (cascade refrigeration, full ATEX explosion protection, SIP) until Stage 3, once you've already validated the core mechanical and process concept at smaller scale and lower stakes. This ordering is the single biggest practical risk-reduction decision in this whole roadmap.

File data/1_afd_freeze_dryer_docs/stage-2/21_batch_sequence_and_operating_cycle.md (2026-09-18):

# 21 — Batch Sequence & Operating Cycle (ISA-88 Structure)

See `diagrams/isa88_batch_structure.png` for the diagram this file explains.

## 1. Why structure the recipe at all, instead of just writing PLC code

The tempting approach is to write one long PLC program that does "step 1, then step 2, then step 3...". It works, right up until you need to change one step, add a second vessel, or explain to someone else what the machine actually does — at which point a flat, unstructured program becomes very hard to safely modify. **ISA-88 (also published as IEC 61512)**, the international batch-control standard, solves this by breaking any batch process into four nested levels that stay the same regardless of what you're actually manufacturing:

```
PROCEDURE  (the whole recipe: "Freeze-Dry Batch")
   └── UNIT PROCEDURE  (a major stage: "Freeze", "Dry", "Discharge", "Clean/Sterilize")
          └── OPERATION  (a meaningful chunk of work: "Primary Drying")
                 └── PHASE  (the smallest reusable, testable unit of logic: "Ramp jacket temperature")
```

**Phases are the important idea.** A phase is small enough to test in isolation, and — this is the payoff — genuinely reusable. "Vacuum-induced freeze" as a phase doesn't care whether it's phase 3 of today's recipe or phase 7 of a future recipe on a second vessel; it's the same tested block of logic either time. This is exactly the property that makes a control system maintainable as it grows, and it's why this structure, not a flat program, is what actually lives inside the BPCS (file 20).

## 2. This machine's cycle, mapped onto that structure

| Unit Procedure | Operations | Phases |
|---|---|---|
| **Freeze** | Charge & Pre-cool | Load product · Start jacket cooldown |
| | Freeze | Vacuum-induced freeze · Hold at set temperature |
| **Dry** | Primary Drying | Ramp jacket temperature · Hold vacuum setpoint · Monitor `PIT-101A`/`PIT-101B` convergence |
| | Secondary Drying | Raise jacket temperature · Hold vacuum · Timed desorption hold |
| **Discharge** | End-of-Cycle | Filter blowback purge · Post-blend in vessel |
| | Discharge | Vacuum release · Open `XV-105` · Confirm empty (`LG-101`) |
| **Clean/Sterilize** | CIP | Pre-rinse · Chemical wash · Final rinse · Air dry |
| | SIP (optional) | Steam admit · Heat-distribution hold · Steam vent/cooldown |

This is the same nine-step cycle already walked through narratively in file 04 §2 — ISA-88 is simply the formal, industry-standard way of writing that same cycle down so a PLC program (and the people maintaining it) can treat each piece as an independent, testable building block instead of one monolithic script.

## 3. How a phase actually behaves (the part that removes the "PLC code = magic" feeling)

Every phase, regardless of what it does physically, follows the same simple state pattern — this is the other half of what ISA-88 standardizes, and it's worth internalizing because it's the same pattern in every phase you'll ever write for this machine:

```
IDLE → (start command) → RUNNING → (complete condition met) → COMPLETE
                             │
                             ├── (hold command) → HELD → (resume) → RUNNING
                             └── (abort/fault condition) → ABORTING → ABORTED
```

Take "Hold vacuum setpoint" as a concrete example: it goes **RUNNING** when the primary-drying operation starts it; it stays RUNNING as long as `PIC-101` is successfully holding pressure near setpoint; it goes to **COMPLETE** when the recipe's time or convergence condition (§4 below) is satisfied; and if `PDT-102` trips high or the SIS fires (file 22), it goes to **ABORTING** and then **ABORTED**, handing control to whatever safe-state logic that fault requires. Every phase in the table above can be described this same way — once you've written the state pattern for one phase, you already understand the shape of all of them.

## 4. A genuinely useful transition condition: ending Primary Drying automatically

Most phase transitions are simple (a timer expires, an operator confirms something). One transition on this machine is worth calling out because it's a real, elegant piece of process logic: the **Primary Drying → Secondary Drying** transition can be driven automatically by watching the gap between `PIT-101A` (true pressure) and `PIT-101B` (Pirani, reads high while water vapor dominates) close to a small, near-zero value (file 06 §3b, file 19 §3) — rather than by guessing a fixed drying time and hoping it's long enough. This is a good first target for your own control logic once you have a working prototype, because it's directly observable and testable against real data (file 15's commissioning plan asks you to log exactly this).

## 5. The full batch as one state diagram

Section 3 showed the generic state pattern *every individual phase* follows. This section shows the top-level state machine for **the whole batch procedure** — the sequence an operator or a supervisory recipe manager actually watches move forward. This is a good artifact to keep in this exact form (Mermaid renders natively in GitHub, most modern documentation tools, and — per your Research Data site's own publishing rules — directly in a `.md` file or inside a `<pre class="mermaid">` block on a published page) rather than only as a picture:

```mermaid
stateDiagram-v2
    [*] --> IDLE
    IDLE --> PRE_STERILIZE: SIP requested
    IDLE --> LEAK_TEST: SIP not required
    PRE_STERILIZE --> LEAK_TEST: SIP cycle complete
    LEAK_TEST --> PRODUCT_CHARGE: rate-of-rise pass
    LEAK_TEST --> IDLE: leak test fail (abort)
    PRODUCT_CHARGE --> PRE_COOL: lid closed & confirmed (ZS-101)
    PRE_COOL --> VACUUM_INDUCED_FREEZING: jacket at freeze setpoint
    VACUUM_INDUCED_FREEZING --> PRIMARY_DRYING: product fully frozen
    PRIMARY_DRYING --> SECONDARY_DRYING: PIT-101A/101B convergence (file 06 §3b)
    SECONDARY_DRYING --> FILTER_BLOWBACK_POSTBLEND: desorption hold time met
    FILTER_BLOWBACK_POSTBLEND --> VACUUM_BREAK: post-blend complete
    VACUUM_BREAK --> STERILE_DISCHARGE: vessel at atmospheric (PSH-101)
    STERILE_DISCHARGE --> CIP_WASH: XV-105 confirmed closed, canister removed
    CIP_WASH --> IDLE: CIP cycle complete

    VACUUM_INDUCED_FREEZING --> ABORT: SIS trip (file 22)
    PRIMARY_DRYING --> ABORT: SIS trip (file 22)
    SECONDARY_DRYING --> ABORT: SIS trip (file 22)
    ABORT --> IDLE: fault cleared & acknowledged
```

A few things worth noticing in this diagram: **`VACUUM_BREAK` uses sterile gas (nitrogen or filtered sterile air), never plant compressed air directly** — this is what keeps the whole discharge aseptic, consistent with Hosokawa's own description of the AFD as a fully sterile, closed process (file 03). **`ABORT` is reachable from every drying-related state, but only the SIS decides when that transition fires** — the BPCS recipe logic itself never overrides a genuine safety trip; it only reacts to one after the fact (file 20 §3). And **`LEAK_TEST` sits before `PRODUCT_CHARGE`**, not after — verifying vacuum integrity on an empty, cleaned vessel before committing real product to a batch is the same discipline file 15's commissioning plan asks for, just now built into the routine production cycle itself rather than only being a one-time commissioning step.

## 6. Recipe vs. equipment — the other half of ISA-88

ISA-88 also separates **what you want to do** (the recipe: target temperatures, hold times, vacuum setpoints — the "formula") from **how the equipment physically does it** (the phase logic wired to `TIC-201`, `PIC-101`, etc.). In practice this means: if you later need to run a *different* product with different hold times and temperatures on the *same* machine, you write a new recipe (a new set of parameters) rather than a new PLC program. This is the standard's biggest practical payoff for anyone planning to iterate on process development (file 16's roadmap) rather than build one fixed, never-changing cycle.

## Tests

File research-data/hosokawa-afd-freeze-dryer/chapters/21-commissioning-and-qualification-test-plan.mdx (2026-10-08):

---
title: "Commissioning, Hydrostatic Testing & Vacuum Leak Qual"
chapterNumber: "21"
slug: "21-commissioning-and-qualification-test-plan"
act: "Commissioning & Maintenance"
actId: "act-5"
readTime: "5 min read"
simulators: []
---

# 21 — Commissioning, Hydrostatic Testing & Vacuum Leak Qual

Hosokawa Micron Test Centre — Multilevel Pilot Process Development & Qualification Facility

This is a practical test plan for bringing your own build to life safely and methodically — modeled on the industry-standard Factory Acceptance Test (FAT) / Site Acceptance Test (SAT) approach, scaled to a self-build project rather than a formal GMP qualification (that's file 14's subject). Run these in order; do not skip ahead to vacuum or thermal testing before the earlier mechanical/electrical checks pass.

## Stage 1 — Pre-power mechanical checks
- [ ] Vessel and all pressure/vacuum-boundary welds visually inspected; NDE reports (if commissioned) reviewed and accepted.
- [ ] Agitator rotates freely through a full revolution by hand, at every point along the cone, with no contact — verify the wall-clearance target (file 05 §3) at multiple heights, not just at one point.
- [ ] All fasteners (lid clamp, support lugs, frame) torqued to spec.
- [ ] All seals/gaskets correctly seated and undamaged.
- [ ] Insulation and cladding installed per design; no exposed cold/hot surfaces left unprotected (file 09 §2).

## Stage 2 — Electrical pre-commissioning (power off, then controlled power-on)
- [ ] Continuity and insulation-resistance ("megger") testing on all motor and heater circuits before first energization.
- [ ] E-stop circuit tested **independently of the PLC** — confirm it cuts power even with the PLC deliberately faulted/powered down.
- [ ] Lid/access interlock tested — confirm the interlock physically prevents (or immediately alarms/stops) operation when the lid is open, and prevents lid release when the interlock condition (e.g., vessel at atmospheric pressure) is not met.
- [ ] All instrumentation calibrated and calibration certificates/records retained *before* first use — this becomes your IQ baseline if you later pursue formal qualification (file 14).
- [ ] Motors bumped individually (very briefly, uncoupled if practical) to confirm correct rotation direction before running against real load.

## Stage 3 — Empty-vessel vacuum and leak testing
- [ ] **Rate-of-rise leak test**: pump the empty vessel down to your target base pressure, isolate the vacuum pump, and record pressure rise over a fixed time (e.g., 10–30 minutes). A well-sealed system should show a slow, near-linear rise dominated by real outgassing, not a rapid climb indicating a gross leak. Compare against your own baseline each time you retest — a rising leak rate over successive tests is an early-warning sign worth investigating before it becomes a process problem.
- [ ] Confirm both Pirani and capacitance-manometer readings agree closely on a dry, empty, leak-tight vessel (file 06 §3b) — a persistent gap here with no water vapor present indicates a gauge calibration issue, not a real pressure difference.
- [ ] Test the vacuum isolation valve and bypass valve (file 06 §5) through all their positions (open/closed/throttled) and confirm position feedback matches actual valve state.
- [ ] Test the vent/break valve — confirm a controlled, not sudden, return to atmosphere.

## Stage 4 — Empty-vessel thermal (TCU/jacket) testing
- [ ] Run the TCU through its full temperature range with the vessel empty, confirming stable control at both temperature extremes and reasonable ramp rates.
- [ ] Confirm jacket supply/return RTDs track each other sensibly (a persistently large ΔT across the jacket at steady state may indicate a flow-distribution problem worth investigating before running product).
- [ ] Confirm no external condensation/frost forms anywhere it shouldn't (insulation effectiveness check, file 07 §4).

## Stage 5 — Agitator functional/load testing
- [ ] Run the agitator empty across its full speed range; record baseline torque/current (file 08 §1) — this becomes your reference for detecting abnormal load during real product runs.
- [ ] Repeat with an inert test load (e.g., an inexpensive placebo granular/powder material, or plain water ice if your first test doesn't need to preserve product-contact cleanliness) approximating your intended batch, to get a realistic loaded-torque baseline *before* your first real product run.

## Stage 6 — Integrated cold/vacuum test (no product, or an inert placebo)
- [ ] Run a full simulated cycle (charge placeholder, freeze, vacuum draw, simulated primary/secondary "drying" — even just holding temperature/vacuum through the equivalent time — vacuum release, discharge) end-to-end, watching for any interaction effects between subsystems that didn't show up in isolated testing (e.g., agitator torque behavior actually at cryogenic temperature, valve actuation timing at real cycle speed).
- [ ] Confirm the material-collector valve/bypass sequencing (file 06 §5, file 03 §2b) behaves as designed through a simulated cycle.
- [ ] Confirm filter blowback/purge functions and correctly routes material to the collection hopper.

## Stage 7 — CIP (and SIP, if equipped) commissioning
- [ ] Run a full CIP cycle and visually verify spray coverage reaches every internal surface (a "riboflavin test" — coating internal surfaces with a UV-fluorescent riboflavin solution before CIP, then inspecting under UV light afterward for any uncleaned "shadow" spots — is a standard, cheap, and very effective industry technique worth using here).
- [ ] If SIP-equipped: run a heat-distribution study (multiple temporary RTDs at various points through the sterilize boundary) confirming every point reaches and holds your target sterilizing temperature for the intended hold time before relying on SIP for anything safety-critical.

## Stage 8 — First real product run
- [ ] Only after Stages 1–7 pass, run your first genuine product batch, instrumented as heavily as practical (log everything), and compare actual sublimation rate, cycle time, and product outcome against your file-11 design calculations — use any significant gap as the trigger to revisit your assumed heat-transfer coefficient, refrigeration sizing, or agitator behavior, rather than assuming the calculation was simply "wrong."

## A note on documentation discipline

Keep dated, signed records of every stage above from day one, even for a hobbyist/prototype build with no regulatory obligation to do so. Two independent reasons: (1) it is simply good engineering practice that will save you enormous troubleshooting time later (file 17), and (2) if this project ever does progress toward file 14's more formal path, this same discipline — done consistently and contemporaneously — is exactly what a later IQ effort would need to either directly reuse or use as a credible starting point.

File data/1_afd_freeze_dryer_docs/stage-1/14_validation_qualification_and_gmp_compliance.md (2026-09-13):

# 14 — Validation, Qualification & GMP Compliance

This file draws the sharpest line in the whole package: **a working freeze dryer** and **a machine legally and technically qualified to manufacture a human drug product** are very different achievements, and the gap between them is mostly paperwork, process, and independent verification — not, at this point, further mechanical engineering.

## 1. The regulatory framework, at a glance

| Element | What it is | Applies to |
|---|---|---|
| **cGMP** (FDA 21 CFR Parts 210/211; EU GMP) | The overarching "current Good Manufacturing Practice" regulatory framework a facility must operate under to legally manufacture drug product for humans | The facility, the process, and every piece of equipment used in it |
| **GAMP 5** | ISPE's risk-based framework for validating computerized/automated systems (the PLC/HMI/SCADA layer, file 08 §3) | Your control system's software, specifically |
| **21 CFR Part 11** | FDA rule on electronic records/signatures — audit trails, access control, e-signatures | Any electronic batch record, data historian, or e-signature workflow on the machine |
| **ASME BPE / PED** | Equipment design standards (files 05, 10) | The physical hardware's sanitary design and, in the EU, its pressure-equipment conformity |
| **ICH Q7 / Q8 / Q9 / Q10** | International harmonized guidelines on GMP for APIs, quality-by-design, quality risk management, and pharmaceutical quality systems respectively | The broader quality system your equipment sits inside |

None of these are things a single piece of equipment "has" in isolation — they describe a **documented, verified system of design, build, test, and ongoing control** around the equipment, executed by (or under) a licensed manufacturer's quality system.

## 2. The qualification lifecycle: DQ → IQ → OQ → PQ

| Stage | Question it answers | When | Typical evidence generated |
|---|---|---|---|
| **URS** (User Requirements Specification) | What must this equipment do? | Before design | A written specification document — batch size, cycle parameters, materials, utilities, regulatory targets |
| **DQ** (Design Qualification) | Does the design meet the URS? | Before procurement/fabrication | Design review record, vendor/fabricator assessment, material compatibility review |
| **IQ** (Installation Qualification) | Was it installed exactly as specified? | At installation, one-time | Serial/model verification, utility-connection checks, calibration baseline for every instrument, P&ID/drawing reconciliation, safety-interlock confirmation |
| **OQ** (Operational Qualification) | Does it operate correctly across its full specified range, including worst-case/boundary conditions? | After IQ, before routine use | Challenge tests at range limits, alarm/interlock functional tests, control-loop tuning verification, negative testing (deliberately trying to make it fail safely) |
| **PQ** (Performance Qualification) | Does it perform consistently under real production conditions? | After OQ, using real/representative product | Multiple consecutive production-representative batches meeting pre-defined acceptance criteria |

**Equipment qualification is a prerequisite for, but distinct from, process validation** — process validation proves that the *manufacturing process* (using this now-qualified equipment) reliably produces drug product meeting its specification; equipment qualification only proves the *machine itself* is installed and behaves correctly.

## 3. What this means concretely for a freeze dryer specifically

- **IQ** would verify, among other things: the vessel/agitator match the fabrication drawings (file 13); every instrument (RTDs, pressure gauges, torque sensor) has a current calibration certificate; utility connections (electrical, compressed air, refrigerant, steam if SIP-equipped) match the design; safety interlocks (file 09 — lid interlock, e-stop circuit) are present and function.
- **OQ** would challenge, at minimum: full vacuum hold (leak-rate test — see file 15), jacket temperature control across its full range including the coldest and hottest setpoints, agitator speed range, CIP cycle parameter accuracy (flow, temperature, time), SIP heat distribution/penetration (if SIP-equipped — a dedicated study confirming every point in the sterilized boundary reaches and holds the required temperature), and every alarm/interlock deliberately triggered to confirm correct response.
- **PQ** would run multiple real (or representative-placebo) batches end-to-end and confirm the resulting product consistently meets its specification (residual moisture, particle characteristics, sterility if aseptic) — this is where the process-development work (finding the right freeze rate, primary/secondary drying temperatures and times, using the physics in file 02) actually gets locked in as a validated recipe.
- **Software validation** (GAMP 5) of the PLC/HMI/historian system runs in parallel, risk-categorized by how customized the software is — a standard, unmodified PLC platform needs less rigor than a heavily custom recipe-management application built on top of it.
- **21 CFR Part 11** compliance is assessed against the specific electronic-record and e-signature functionality actually implemented — audit trail completeness, user-access control, and e-signature binding are the most commonly cited gap areas in FDA inspection findings, per current industry validation literature.

## 4. Where this package's own claims stop

- Everything in files 02–11 describes sound, citable engineering practice and, where used, Hosokawa's own patent-disclosed design detail. **None of it constitutes a URS, a DQ record, or any part of an actual qualification package** — those documents must be written against your specific design, your specific intended product, and your specific regulatory jurisdiction, typically by or with a quality/validation professional.
- A prototype or even a very well-built pilot-scale replica constructed by following this package is a **learning and engineering-development platform**. It does not become GMP-compliant equipment by virtue of being well-built — that status is conferred by the qualification and quality-system process above, run inside a licensed manufacturing organization, not by the hardware alone.
- If your ultimate goal genuinely is producing a drug product for human or animal use, the realistic path is: use this package (and the roadmap in file 16) to build engineering competence and a working prototype, then partner with (or be employed by/build within) an organization that has, or is building, the full quality system, regulatory relationships, and licensed facility this framework requires — not to attempt to self-certify a home-built machine as GMP equipment.

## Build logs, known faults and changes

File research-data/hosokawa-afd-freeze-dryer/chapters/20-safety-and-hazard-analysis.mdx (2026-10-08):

---
title: "Safety Analysis, HAZOP, ATEX & Explosion Protection"
chapterNumber: "20"
slug: "20-safety-and-hazard-analysis"
act: "Electrical, Controls & Safety Automation"
actId: "act-4"
readTime: "7 min read"
simulators: []
---

# 20 — Safety Analysis, HAZOP, ATEX & Explosion Protection

**Read this file before touching metal, refrigerant, or a vacuum pump.** A freeze dryer combines four independently serious hazard categories in one machine: vacuum/implosion, refrigeration, electrical, and combustible dust. None of them are exotic — all are well understood and well controlled in industry — but all are unforgiving of shortcuts.

## 1. Vacuum / implosion hazard

- A vessel under vacuum has the **full weight of the atmosphere (~1 bar, ~14.7 psi, ~1 kg/cm²) pushing inward on every square centimeter of its surface** — for a modest 300 mm diameter lid, that's on the order of a metric ton of net inward force. Unlike a pressure vessel's failure mode (which tends to be a controlled leak or a localized rupture), a **thin-walled vessel failing under external pressure buckles suddenly and catastrophically** — it does not fail gracefully, and flying/collapsing metal and glass (sight glasses!) is a real hazard.
- **Design implication**: the vessel, its jacket, and every viewport/sight glass must be designed to the external-pressure rules in file 05 §5 (ASME Section VIII UG-28 through UG-30, or the equivalent PED/EN 13445 route in Europe) with proper safety margin — this is not a place to "eyeball it thicker" without an actual buckling calculation, because buckling resistance does not scale linearly or intuitively with wall thickness (it's closely tied to shell geometry, unsupported length, and material modulus).
- **Sight glasses and viewports** are a disproportionately common real-world failure point on vacuum equipment — always use glass specifically rated by its manufacturer for the vessel's full vacuum and temperature range, never a standard (pressure-rated-only, or unrated) sight glass.
- **Never work on a vessel under vacuum without a vacuum-rated relief/vent path** that can be opened (manually, if needed) to bring the vessel to atmosphere before any access panel, lid clamp, or fitting is loosened. Interlock lid/access-panel opening so it cannot occur while the vessel is below atmospheric pressure (a pressure-switch-driven mechanical or electrical interlock, not a "remember to check the gauge" procedure).

## 2. Refrigeration hazards

- **High-side refrigerant pressure**: even at the "low temperature" end refrigeration systems operate at, the high-pressure side of a vapor-compression cycle can reach many bar — refrigerant piping, receivers, and components must be rated and installed per the applicable refrigeration piping code (e.g., ASHRAE 15 / IIAR guidance for ammonia systems) and by, or under the direct supervision of, someone qualified in refrigerant handling.
- **Cascade system natural refrigerants** (ethane, propane, ammonia — all mentioned in file 06 as legitimate low-GWP options) bring their own specific hazards: **ethane and propane are flammable** (a genuine ignition/fire hazard if leaked into a confined equipment room), and **ammonia is toxic and corrosive** at leak concentrations well below its flammable limit. None of these is a "safer because natural" free pass — each demands its own specific detection, ventilation, and handling protocol, and jurisdictions regulate refrigerant charge sizes and machine-room requirements accordingly (check local refrigeration and building codes before selecting a refrigerant).
- **Cryogenic contact hazard**: jacket surfaces, piping, and any direct LN₂/dry-ice freezing line (file 05 §2) can reach temperatures that cause instant frostbite/cold-contact burns on unprotected skin. Insulate and label all cold surfaces (file 07 §4); use appropriate PPE (insulated gloves, face shield) when handling LN₂ or dry ice directly.
- **Asphyxiation from LN₂ or CO₂ off-gassing**: if using direct liquid-nitrogen or dry-ice injection freezing (file 05 §2, one of the two methods the 2003 patent discloses), the vented nitrogen or CO₂ gas can displace breathable oxygen in an enclosed room — an oxygen-deficiency monitor in the equipment room is standard, non-optional practice anywhere bulk cryogen is used or vented, not a freeze-dryer-specific requirement but one this design directly triggers.

## 3. Electrical hazards

- Standard industrial-electrical safe practice applies throughout (lockout/tagout before any panel work, correctly rated and installed disconnects, properly sized and protected circuits) — nothing exotic here, but nothing to skip either given the number of motors, heaters, and control circuits involved (file 08 §4).
- **E-stop circuits must be hardwired independently of PLC logic** (file 08 §4) — a software-only emergency stop is not an acceptable safety control for equipment with rotating machinery, refrigerant, and vacuum energy present simultaneously.
- Equipment in dust-hazard zones (below) must be correctly ATEX/hazardous-area rated — a standard-rated motor or junction box is a real ignition source if installed where it shouldn't be.

## 4. Combustible dust hazard (ATEX / NFPA 652)

This is the hazard category most specific to *this particular machine's product*, and easy to underestimate because "it's just powder."

- **Freeze-dried pharmaceutical powders can be combustible dusts.** Fine, dry, organic (or metal) powder dispersed in air, given an ignition source and confinement, can explode — the same physics behind well-known grain-elevator and flour-mill disasters. The relevant standards are the EU's **ATEX directive** (2014/34/EU, equipment; plus the related workplace directive) and, in the US, **NFPA 652** ("Fundamentals of Combustible Dust") together with NFPA 654 for the specific process-industry application.
- **A Dust Hazard Analysis (DHA)** — a documented, systematic assessment of where combustible dust could accumulate or become airborne, and what ignition sources are present — is a required deliverable under NFPA 652 for any facility handling combustible dust, and the equivalent DSEAR/ATEX risk assessment is required in the EU/UK. This should be done for your specific product/powder, not assumed generically, because explosibility (characterized by `Kst`, the dust deflagration index, and `Pmax`, maximum explosion pressure, both measured by standardized dust testing) varies enormously by material — reference `Kst` figures published in industry literature range from roughly 80–200 bar·m/s for common organic powders (sugar, starch, flour-like materials) up to 300–700 bar·m/s for reactive metal powders, with corresponding minimum ignition energies that can be extremely low (single-digit millijoules) for the more sensitive materials.
- **The AFD's own architecture concentrates this risk at a specific, identifiable location**: the material collector/filter housing and the product discharge point (file 06 §4) are exactly where dry powder is most concentrated in the highest-velocity, most-dispersed state in the whole process — this is precisely the zone to prioritize for ATEX-zone classification (Zone 20/21/22 per the standard dust-zone system), ATEX-rated equipment selection (file 08 §4), and physical explosion protection.
- **Explosion protection layers**, standard industry practice, roughly in order of preference: (1) **inherently safer design** — minimize dust generation/dispersion and eliminate ignition sources first; (2) **explosion venting** (rupture panels/flame-free vents that relieve an explosion's pressure to a safe location before the vessel itself fails) — the lower-cost, passive option, generally suitable for less energetic (lower Kst) dusts; (3) **explosion suppression** (fast-acting detectors trigger a suppressant injection within milliseconds of ignition, before pressure builds) — required for confined/indoor equipment or more energetic dusts where venting to outside isn't practical; (4) **isolation** (fast valves or chemical barriers that stop a deflagration from propagating between interconnected vessels). A qualified process-safety engineer should size and specify actual explosion protection hardware for your specific product and equipment geometry — this package gives you the framework and vocabulary, not a substitute for that sizing exercise.
- **Ignition source control** inside and around the dust-handling zone: no unrated electrical equipment (above), static-dissipative construction and bonding/grounding of all conductive parts (fine powder handling generates static charge readily), and no hot surfaces above the powder's minimum ignition temperature.

## 5. Pressure-relief and general process safety

- Beyond vacuum-side concerns (§1), any steam (SIP) piping and the jacket's heating circuit need conventional pressure-relief devices sized per the applicable piping/vessel code for their respective operating pressures — standard practice, not unique to this machine.
- **Interlocks worth building in from the earliest prototype, not added later**: lid/access cannot open under vacuum (§1); agitator cannot start unless the lid is confirmed closed and interlocked; SIP steam cannot be admitted unless required pre-conditions (e.g., correct valve line-up) are met; e-stop immediately cuts agitator, heaters, and (where safe to do so) isolates refrigerant compressors.
- **Documented, written safe operating procedures and a permit-to-work approach for any refrigerant, cryogen, or confined-space-adjacent maintenance task** — this is standard industrial-safety practice, and doubly worth insisting on for a first-time or small-team build where there's no existing plant safety culture to fall back on by default.

## 6. Where this package draws the "educational/prototype" line

Everything above describes real hazards and real, standard mitigation practice. It does **not** constitute a completed hazard analysis, a stamped/certified pressure-vessel design, or a permit to operate refrigeration or process equipment in any given jurisdiction — those all require qualified, often licensed, professional sign-off specific to your actual design, location, and applicable local codes. Treat this file as the checklist of *what categories of hazard you must get qualified help for*, not as that qualified help itself.

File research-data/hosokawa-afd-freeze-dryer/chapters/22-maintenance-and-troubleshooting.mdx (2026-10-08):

---
title: "Preventative Maintenance, Seal Overhaul & Diagnostics"
chapterNumber: "22"
slug: "22-maintenance-and-troubleshooting"
act: "Commissioning & Maintenance"
actId: "act-5"
readTime: "5 min read"
simulators: []
---

# 22 — Preventative Maintenance, Seal Overhaul & Diagnostics

## 1. Preventive maintenance schedule (generic starting point — tune against your own experience)

| Item | Check | Suggested frequency |
|---|---|---|
| Vacuum system leak rate | Rate-of-rise test (file 15 Stage 3) | Before each batch, or weekly at minimum |
| Agitator seal / magnetic coupling | Visual inspection; for shaft seals, check for wear/leakage signs | Monthly, or per manufacturer's wear-part schedule |
| Agitator wall clearance | Physical check (where accessible) or trend agitator torque/current for gradual changes suggesting wear or buildup | Quarterly, or immediately if torque baseline drifts |
| Lid/port seals and gaskets | Visual inspection for compression set, cracking, or chemical degradation | Monthly; replace on any visible degradation, not just on failure |
| Filter element (material collector) | Differential pressure trend (file 08 §1); physical inspection/replacement | Per ΔP trend and/or product-contact hygiene schedule |
| TCU heat-transfer fluid | Check for degradation (silicone oil can oxidize/degrade over time and high-temperature exposure, especially post-SIP-adjacent heat cycling) | Per fluid manufacturer's service-life guidance |
| Refrigeration system | Refrigerant charge/pressure check, oil level (if applicable), condenser cleanliness | Per refrigeration technician's standard schedule; **refrigerant work requires appropriately certified personnel** (file 09 §2) |
| Calibration (all instruments) | Recalibrate against a traceable standard | Per instrument manufacturer's recommendation, typically annually, more often for critical control instruments |
| Structural frame / vibration isolators | Visual inspection, fastener torque check | Semi-annually |
| Electrical panel | Thermal imaging scan of connections (loose connections show as hot spots), insulation resistance spot-checks | Annually |
| ATEX-zone equipment | Confirm rated equipment remains correctly installed/undamaged; confirm no unrated equipment has been introduced into the zone | Per site electrical-safety schedule, and after any modification |

## 2. Troubleshooting matrix

| Symptom | Likely causes (roughly most → least common) | Where to look |
|---|---|---|
| Vacuum won't reach target base pressure | Leak (seal, gasket, valve stem); pump underperforming/worn; outgassing from a dirty/contaminated vessel | File 15 Stage 3 leak test methodology; file 06 §3 pump selection; recheck CIP effectiveness |
| Pirani and capacitance manometer readings diverge persistently, even on an empty/dry vessel | Gauge calibration drift; gauge contamination | Recalibrate per instrument schedule (§1 above); file 06 §3b |
| Pirani/capacitance gap never closes during a "finished" batch | Primary drying genuinely incomplete — product still subliming | Extend primary drying time; revisit file 11's sublimation-rate calculation against your actual measured jacket ΔT and heat-transfer coefficient |
| Product temperature exceeds intended limit during primary drying | Jacket temperature setpoint too aggressive for this product; insufficient vacuum (chamber pressure too close to the product's ice vapor pressure, reducing the driving force) | File 02 §3 (collapse temperature); reduce jacket setpoint; verify actual chamber pressure via capacitance manometer, not just Pirani |
| Agitator torque/current trending upward over multiple batches | Product buildup/caking reducing effective wall clearance; seal degradation increasing friction; bearing wear | File 10 §3; inspect agitator and wall clearance at next planned access; review CIP effectiveness |
| Agitator torque spikes sharply during freezing stage | Expected to some degree (this is the normal signature of the mass solidifying, file 04 step 3) — investigate only if spikes are large enough to trip a drive fault or exceed your established baseline significantly | File 15 Stage 5 baseline data is your reference point |
| Uneven/inconsistent drying across a batch | Agitation not achieving uniform bed turnover (geometry or speed issue); jacket temperature not uniform around the vessel (TCU flow-distribution issue) | File 05 §3 agitator design; file 08 §1 jacket RTD comparison (supply vs. return, and if multiple zones, zone-to-zone) |
| Filter differential pressure rising rapidly / frequent blowback needed | Product particle size finer than expected for the filter media selected; filter media degrading | File 06 §4; reconsider filter mesh rating for your specific product |
| CIP cycle leaves visible residue (riboflavin-test "shadows," file 15 Stage 7) | Spray coverage gap (nozzle placement/orientation); insufficient flow, temperature, or chemical concentration; a genuine dead-leg or crevice in the piping/vessel design | Review nozzle coverage geometry; check CIP skid parameters against design cycle; review for BPE sanitary-design violations (file 05 §4, file 08 §6) introduced during fabrication |
| SIP fails to reach sterilizing temperature at some monitored point | Steam trap malfunction; undersized steam supply; a cold spot / dead leg in the piping | Heat-distribution study data (file 15 Stage 7); review piping isometrics (file 13) for dead legs |
| Refrigeration system can't reach target low-stage temperature | Undersized for actual heat load; refrigerant charge low (leak); cascade heat exchanger fouled/undersized | File 06 §2 sizing review; refrigeration technician inspection (file 09 §2 — certified personnel required) |
| Nuisance e-stop / interlock trips | Sensor drift or miscalibration; genuine intermittent fault worth taking seriously rather than bypassing | **Never bypass a safety interlock to "solve" nuisance tripping** — investigate and fix the root cause (file 09 §5) |

## 3. A general troubleshooting principle worth stating explicitly

Every symptom above should be diagnosed against the **baseline data you deliberately collected during commissioning** (file 15) — empty-vessel torque, calibration certificates, leak rate, jacket ΔT at steady state, and so on. Troubleshooting a system with no recorded baseline is troubleshooting blind; the discipline recommended in file 15's closing note pays for itself here.

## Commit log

2026-09-13 feat: Research Data Lab v1 - Hosokawa AFD Freeze Dryer interactive lab
    [AFD_replica_BOM.xlsx]
2026-09-16 feat(exhibit): dynamic interactive URL buttons, in-page speech highlighting with auto-scroll, minimizable floating narrator, export modal, and favicon
2026-09-17 restructuing for stage 2
    [AFD_replica_BOM.xlsx]
2026-09-17 feat(act-v): integrate Stage 2 P&ID and automation chapters 19-22, fix Word export filename, enforce 20mm uniform margins, add theme toggle and search shortcuts
2026-09-17 refactor(architecture): replace cluttered multi-tab with clean card-based connected subsystem flowchart, fix hydration rounding, and add navbar theme label
2026-09-17 feat(stage-2): master engineering prompt addressing freezing physics, jacket thermal architecture, and CAD interface
2026-09-17 feat(performance): 120fps hardware acceleration, zero-flicker rendering, anti-jitter, and mobile navigation suite
2026-09-17 fix(diagrams): eliminate wire overlaps, add 6 distinct dynamic subsystem colors, and enforce WCAG AAA contrast
2026-09-17 feat(simulators): high-fidelity 3D fabricated machine model with cutaway, OrbitControls, and fullscreen CAD studio
2026-09-17 feat(voice-engineering): add edge neural human tts, dynamic F0 acoustic telemetry, DSP equalizer, and remove duplicate minimize button
2026-09-17 fix(webgl-tts): resolve zero-size framebuffer errors and fix chapter audio routing and playback
2026-09-18 feat(voice-scope): hide raw Hz numbers in normal view and add expandable acoustic analyzer with multiple representations, time & Hz axes, and calibrated limits
2026-09-18 feat(stage-2): align site with complete Stage 2 research package, 25 chapters, CAD nozzle schedule, and interlocks
    [AFD_replica_BOM.xlsx, cause_and_effect_matrix.csv, io_list.csv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]
2026-09-18 Eliminate text-cluttered diagrams across project, embed all images, replace raw mermaid with interactive FullBatchProcedureChart, add EngineeringDiagramsGallery, and ground voice scope at 0.0 Hz
2026-09-18 feat(ui): sticky table headers, floating horizontal scrollbar, floating AI voice button, and chapter navigation badges
2026-09-18 feat(navigation): ensure guaranteed bottom scroll clearance for Next/Prev chapter buttons and add interactive equation workbenches
2026-09-19 feat(voices): add Google Gemini Umbriel and Gacrux dual-voice narrators - Umbriel (Andrew Multilingual Neural): warm baritone -3Hz rate 0.95x - Gacrux (Ava Multilingual Neural): crisp alto +1Hz rate 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
2026-09-26 fix(sizing-suite): resolve CAD callout overlap and dynamic slider bidirectional coupling
2026-09-27 feat(narrator): add reader monitor panel with chunk sync and skip fix
    - NarratorContext: expose speechChunks, currentChunkIndex, currentChunk,
    readerPanelOpen state and seekToChunk() for panel integration
    - NarratorDeck: add Monitor toggle button to control bar
    - ExhibitReader: isolate table-row highlight from paragraph highlight
    to prevent mid-table skip/jump regression
    - voice-engine: replace em-dash encoding issues with hyphens (ASCII safe)
    - RealtimeVoiceGraph: fix em-dash encoding artifacts in display strings
2026-09-27 fix(reader-monitor): convert panel from sidebar column to fixed floating drawer
    Previously the panel rendered as a sticky aside column in the flex layout,
    consuming page width at all times and covering the content even when closed.
    Changes:
    - ReaderTeleprompterPanel: complete rewrite as fixed z-[45] overlay
    - Closed state: renders nothing (zero DOM footprint, no sidebar gap)
    - Open state: slides up from above NarratorDeck (bottom: ~96px)
    - Width: full-width on mobile, 420px pinned to right on sm+
    - Max-height: 55vh so it never covers the entire page
    - Hero spotlight section is independently collapsible via chevron
    - Compact sizing throughout for better mobile ergonomics
    - Remo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
2026-09-27 fix(narrator+header): fix sentence fragmentation and squished navbar
    narrator/voice-engine:
    - Improved sentenceRegex to treat parenthetical clauses as part of the
    enclosing sentence - previously '(inventors: ... Imole).' was split as
    a standalone 'Imole).' chunk because the regex broke at ')' before '.'
    - New regex keeps (...) groups intact and allows closing brackets/quotes
    after the terminal punctuation before splitting
    - Raised minimum chunk skip-guard from 3 to 8 chars to prevent any
    remaining sub-word fragments from being spoken or shown as segments
    layout/Header:
    - Remove fixed h-11 heights from all navbar buttons; use py-1.5 instead
    - Persona name label: hidden until lg (was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
2026-09-27 Searched for "<table" Searched for "StickyMarkdownTable" Viewed StickyMarkdownTable.tsx:1-73 Searched for "renderInline" Viewed ExhibitReader.tsx:1100-1150 Searched for "render" Viewed ExhibitReader.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
2026-09-27 Viewed NarratorContext.tsx:525-585 Ran command: `powershell -Command "Get-ChildItem -Path 'e:\git_desktop\research-data-lab' -Recurse -Filter '*tts*' | Select-Object FullName | Format-Table"` Viewed 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
2026-09-27 feat(webinar): integrate 33 unique Nauta webinar slides, deduplicated PPT/PDF deck, interactive viewer, and categorized schematics into Research Lab
2026-09-27 feat(webinar): add Basics of Material Drying 45-slide deduplicated presentation, dual-deck portal, and thermodynamic synthesis
2026-09-27 Sharpen site chapters with authentic Hosokawa CAD WIP/CIP spray data, 10:1 motor kinematics, drying thermodynamics, and remove obsolete file inventory clutter
2026-09-27 Viewed PhaseDiagramExplorer.tsx:1-160 Viewed PhaseDiagramExplorer.tsx:161-329 Viewed physics.ts:1-100 Viewed physics.ts:100-140 Ran command: `python -c " import math
    def p_sub(t_c):
    T = t_c + 273.15
    if T <= 0: return 1e-12
    return 6.1112 * math.exp(-6149.1 * (1.0/T - 1.0/273.16))
    def p_vap(t_c):
    if t_c < 0.01: return p_sub(t_c)
    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
2026-09-27 Eliminate fullscreen hover flicker via absolute HUD overlay and add sleek interactive stage stepper
2026-09-27 feat: deeply sharpen research lab with Hosokawa CAD specs, eliminate meta-fluff, upgrade thermodynamic phase diagram and vessel kinematics
2026-10-04 Searched for "theme" Viewed VacuumVsFreezeDryerStudio.tsx:1-100 Viewed VacuumVsFreezeDryerStudio.tsx:150-300 Viewed VacuumVsFreezeDryerStudio.tsx:350-500 Created VacuumVsFreezeDryerStudio.tsx Ran com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
    [hosokawa_afd_canonical_bfd.dxf, hosokawa_afd_temp_pressure_cycle.dxf, hosokawa_afd_unbundled_pfd.dxf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]
2026-10-08 Ran command: `python -c " import os
    p = r'e:\git_desktop\research-data-lab'
    for item in os.listdir(p):
    if os.path.isdir(os.path.join(p, item)):
    print('Dir:', item)
    "`
    Ran command: `python -c "
    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
2026-10-08 Ran command: `python -c " import os p = r'e:\git_desktop\research-data-lab\app' for root, dirs, files in os.walk(p): for f in files: print(os.path.relpath(os.path.join(root, f), p)) "` Viewed page.ts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
2026-10-08 Ran command: `python -c " import os, re
    base_dir = r'e:\git_desktop\research-data-lab\research-data\hosokawa-afd-freeze-dryer\chapters'
    target_files = [
    '00-readme.mdx',
    '01-beginner-foundations-and-glossary.mdx',
    '14-validation-qualification-and-gmp-compliance.mdx',
    '16-build-roadmap-prototype-to-pharma-capable.mdx',
    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
2026-10-08 Searched for "CONDENSER COMPARISON MATRIX" Viewed 03-process-flowsheets-bfd-and-pfd.mdx:170-215 Ran command: `python -c " import os, re
    cdir = r'research-data/hosokawa-afd-freeze-dryer/chapters'
    files = sorted(os.listdir(cdir))
    findings = []
    for f in files:
    if not f.endswith(('.mdx', '.md')): continue
    fpath = os.path.join(cdir, f)
    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
